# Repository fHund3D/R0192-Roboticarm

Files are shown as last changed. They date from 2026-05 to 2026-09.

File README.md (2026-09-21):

# Roboticarm-R0192




Der **R0192** ist ein 6-Achsen-Roboterarm, der auf einem hybriden System aus SteadyWin- und RobStride-Aktuatoren basiert. Dieses Repository enthält das vollständige ROS 2 Jazzy-Ökosystem für die CAN-Bus-Kommunikation, die Hardware-Abstraktion, die Bahnplanung via MoveIt 2 sowie ein Arduino-basiertes Hall-Sensor-Homing.

Die gesamte Steuerungslogik (MoveIt 2, ros2_control, CAN-Treiber) läuft auf einem **Raspberry Pi 5**. Eine zentrale **Betriebszustands-Maschine** (`robot_state_manager`) koordiniert Motor-Enable, Jogging, MoveIt-Ausführung, Homing und Notaus als sich gegenseitig ausschließende Zustände. Bedient wird der Arm über ein **RViz-Jog-Panel**, das gezielt zu einem Teach-Pendant-Ersatz ausgebaut wird (später ggf. durch ein echtes Hardware-Teach-Pendant ersetzbar); ein **Web-Interface** (`r0192_remote`) bleibt eine optionale Zukunftsoption. Foxglove Studio spielt nur eine kleine Rolle zum Debuggen. **Alle sechs Aktuatoren sind inzwischen beschafft und montagebereit**; softwareseitig sind die GDS68- und RS05-Antriebsstränge an je einer Achse verifiziert, die Inbetriebnahme der übrigen Achsen läuft.

---

## 🚀 Projekt-Roadmap

### Software (ROS 2 & OS)
- [x] OS-Setup: Ubuntu 24.04 & ROS 2 Jazzy Installation
- [x] Workspace & Paketstruktur initialisiert
- [x] Treiber-Integration: SteadyWin GDS68 (Achse 1–3)
- [x] Treiber-Integration: RobStride RS05 (Achse 4–6)
- [x] CAN-Kommunikation & Hardware Interface (ros2_control, 100 Hz, Closed-Loop)
- [x] URDF/XACRO Modellierung inkl. 3D-Visualisierung & Kollisionsgeometrien
- [x] MoveIt 2 Integration — Bahnplanung & Trajektorienausführung auf Achsen 1 + 4 verifiziert
- [x] Encoder-Homing beim Start (Hardware Interface setzt internen Nullpunkt)
- [x] `foxglove_bridge` in Bringup integriert (Debug-Tool, Port 8765, `use_foxglove:=true`)
- [x] **Homing-Sequenz** mit TLE4905L Hall-Sensoren — Arduino-Firmware (Achse 1) + ROS-Service `/homing` in `r0192_hardware` eingebettet; zweiseitiger Kantenanlauf (Kante A → Überfahren → Kante B → Mitte) implementiert
- [x] **RViz Jog-Panel / Teach-Pendant** (`r0192_rviz_plugins`) über MoveIt Servo: 3 Modi (Joints / Cartesian / Tool), Speed-Slider, Press-and-Hold
- [x] **Zentrale Zustandsmaschine** (`robot_state_manager` + `r0192_interfaces`): 5 exklusive Zustände DISABLED / HOLD / JOG / MOVEIT / HOMING via `/set_robot_state` + `/robot_state`
- [x] **Notaus** (`/e_stop`) — erzwingt DISABLED aus jedem Zustand, latchender Treiber-Torque-Cut (GDS68 `Estop()`, RS05 stop) + Treiber-Reset (`/robot_reset` → `Clear_Errors`) zur Wiederinbetriebnahme
- [x] **Programm-System** (`r0192_program_executor`) — industrielle Trennung Engineering (YAML in VS Code, JSON-Schema-Validierung) ↔ Operations (RViz-Run-Panel „R0192 Program"). Action `/execute_program`, KRL/Pilz-Steps `ptp`/`lin`/`circ` (+ Legacy `move_j`/`move_l`/`wait`), Stop-at-each-point **und** Pilz-Blend-Modus mit `c_dis`, Pause/Resume/Speed-Override, Punkt-Teach. Ersetzt für die Programmierung das ursprünglich geplante Web-Interface
- [ ] **Aktuell: Hardware-Test Homing** — Arduino + Magnet an Achse 1 anschließen und end-to-end validieren
- [ ] **Aktuell: RViz-Jog-Panel zum Teach-Pendant ausbauen** — bedienerfreundlich möglichst nah an ein echtes Teach-Pendant (später ggf. durch ein Hardware-Pendant ersetzbar); ein Web-Interface (`r0192_remote`) bleibt optionale Zukunftsoption
- [ ] **Hardware-Notaus über Schütz/Relay** — schaltet die 48-V-Versorgung hart ab (zusätzlich zum latchenden Treiber-Torque-Cut); laufenden Homing-Sweep abbrechen
- [ ] Echtzeit-Optimierung (RT-Kernel & CPU-Shielding auf RPi 5)

#### Projektstruktur

```
roboticarm_r0192_ws/
├── src/
│   ├── r0192_bringup/         # Bringup Sequenz (real + simuliert)
│   ├── r0192_canbus/          # CAN-Bus Treiber: GDS68, RS05, CanCommunication
│   ├── r0192_controller/      # JTC-Konfiguration, manueller Slider-Node
│   ├── r0192_description/     # URDF/XACRO, STL-Meshes, RViz-Konfiguration
│   ├── r0192_interfaces/      # Custom msgs/srvs: RobotState, SetRobotState
│   ├── r0192_hardware/        # ros2_control HW-Interface + robot_state_manager
│   ├── r0192_moveit/          # MoveIt 2: SRDF, Kinematik, Planung, Servo, Launch
│   ├── r0192_rviz_plugins/    # RViz Jog-Panel / Teach-Pendant (Operator-Panel)
│   └── r0192_remote/          # (Geplant) Web-Interface als Operator-Pendant
├── doku/                      # Datenblätter & Treiber-Dokumentation
├── build/                     # Build-Artefakte (ignoriert)
├── install/                   # Install-Artefakte (ignoriert)
└── log/                       # Logs (ignoriert)
```

#### System-Architektur

```
RViz Jog-Panel  /  Web-Interface (geplant)        Debug-Tools (optional)
  │  /set_robot_state, /e_stop                     RViz  ◄──  ROS-Topics
  │  /robot_state (latched)                        Foxglove ◄─ foxglove_bridge (:8765)
  ▼
robot_state_manager  (zentrale Zustandsmaschine)
  │  koordiniert: /robot_enable, switch_controller, pause_servo, /homing
  ├──────────────► MoveIt 2 + Servo
  │                     │
  ▼                     ▼
ros2_control (100 Hz, Closed-Loop)  ──►  arm_controller / gripper_controller
                 │
         R0192SystemHardware
          ├─ /robot_enable Service (Motor-Torque an/aus)
          ├─ /homing Service (eingebettet, HomingController)
                 │
    ┌────────────┴────────────┐
GDS68Driver              RS05Driver
(Achsen 1–3)             (Achsen 4–6)
    └────────────┬────────────┘
             SocketCAN (can0, 1 Mbit/s)
             MKS CANable Pro → Motoren
                 │
    Arduino Uno R3 (je 1 pro Achse)
    TLE4905L Hall-Sensor + MCP2515
    Homing-Node (CAN-ID 0x100, Codes in Data[0]: CMD_ARM/DETECTED/ERROR)
```

#### Betriebszustände (Robot State Manager)

Der `robot_state_manager` ist die *Single Source of Truth* für den Betriebszustand. Vorher war der Zustand implizit über drei verstreute Flags verteilt (`motors_enabled_`, Homing-aktiv, Servo-Pause) — jetzt 5 exklusive Zustände mit erzwungenen Übergängen:

| Zustand | Motor-Torque | `arm_controller` | Servo | Bedeutung |
| :--- | :--- | :--- | :--- | :--- |
| `DISABLED` | aus | inaktiv | pausiert | Idle, drehmomentfrei (Startzustand) |
| `HOLD` | an | inaktiv | pausiert | Servos an, Hardware hält letzte Soll-Pos |
| `JOG` | an | aktiv | aktiv | Teach-Pendant über MoveIt Servo |
| `MOVEIT` | an | aktiv | pausiert | move_group darf Trajektorien ausführen |
| `HOMING` | an | (Homing managed) | pausiert | Homing-Sequenz läuft |

Übergänge: `DISABLED ⇄ HOLD`, und aus `HOLD` heraus `→ JOG / MOVEIT / HOMING` (jeweils zurück nach `HOLD`). `/e_stop` erzwingt `DISABLED` aus **jedem** Zustand und kappt das Drehmoment **auf Treiber-Ebene** (GDS68 `Estop()` 0x002 latchend, RS05 stop). Die Treiber sind danach bewusst in einem Fehlerzustand „gefangen" — `/robot_reset` (→ Hardware `Clear_Errors` / RS05-Fault-Clear) löst das, erst dann ist `DISABLED→HOLD` wieder erlaubt. Clients (RViz-Panel, künftiges Web-Interface) steuern ausschließlich über `/set_robot_state` und spiegeln das latched `/robot_state` — nie direkt `/robot_enable` / `/homing` / `pause_servo`.

### Hardware & Mechanik
- [x] Kinematische Auslegung & Motorauswahl
- [x] Grobes mechanisches Design (CAD)
- [x] Beschaffung **aller 6 Aktuatoren** abgeschlossen (4× SteadyWin GIM @ GDS68, 2× RobStride RS05)
- [ ] Detail-Konstruktion & Optimierung der Steifigkeit
- [ ] Full-Scale 3D-Druck Prototyping (PLA/PETG)
- [ ] **Geplant:** Substitution kritischer Strukturbauteile durch CNC-Aluminium
- [ ] **Steuerungs- & Versorgungsschrank** (Item-/Profil-5-Alu, 20×20) — separates Gehäuse für beide Netzteile, ODrive Regen Clamp & Raspberry Pi als externe Steuerung/Stromversorgung des Arms

### Elektronik (PCB Design)
- [x] Schaltungskonzept & Leistungsplanung
- [x] Design Daisy-Chain PCB (PCB 2) - *Draft*
- [ ] Design Breakout-Board (PCB 1) - *Main Power Distribution*
- [ ] Not-Aus-Schütz 48 V aufbauen (Konzept steht: [`doku/estop_konzept.md`](doku/estop_konzept.md))
- [ ] PCB-Fertigung (PCBWay) & Bestückung
- [ ] Systemintegration & EMV-Tests

---

## 🛠 Technische Spezifikationen

### Achskonfiguration

> **Alle sechs Aktuatoren sind beschafft.** Achsen 1–4 nutzen SteadyWin-GIM-Motoren am **GDS68**-Treiber (11-bit-Standard-CAN), Achsen 5–6 RobStride **RS05** (29-bit-Extended-CAN). Achse 4 wurde von RS05 auf einen **GIM6010-8** umgestellt (24 V, ohne Bremse — der zuerst beschaffte Motor); Achsen 1–3 sind die 48-V-Varianten **mit Bremse** — sie legen den größten Weg zurück und tragen die größte Last; die Bremse hält sie stromlos in Position und verhindert ein Zusammenfallen des Arms ohne Strom. Achsen 5–6 sind RS05 @ 48 V.

| Achse | Motor | Treiber | Spannung / Bremse | Besonderheit | Lagerung | Status |
| :--- | :--- | :--- | :--- | :--- | :--- | :--- |
| **Axis 1** | [GIM6010-8](https://openelab.de/products/steadywin-gim6010-8-planetengetriebemotor?variant=54009308873041) | GDS68 | 48 V · mit Bremse | High Torque Base | [Kreuzlager RU66](https://de.aliexpress.com/item/1005008094900625.html) | ✅ Vorhanden |
| **Axis 2** | [GIM8108-8](https://openelab.de/products/steadywin-gim8108-8?variant=54041139609937) | GDS68 | 48 V · mit Bremse | Hauptausleger | [Kreuzlager RU42](https://de.aliexpress.com/item/1005008094900625.html) | ✅ Vorhanden |
| **Axis 3** | [GIM6010-8](https://openelab.de/products/steadywin-gim6010-8-planetengetriebemotor?variant=54009308873041) | GDS68 | 48 V · mit Bremse | Ellenbogen | - | ✅ Vorhanden |
| **Axis 4** | [GIM6010-8](https://openelab.de/products/steadywin-gim6010-8-planetengetriebemotor?variant=54009308873041) | GDS68 | 24 V · ohne Bremse | Zuerst beschaffter Motor (ersetzt RS05) | - | ✅ Vorhanden |
| **Axis 5** | [RS05](https://openelab.de/products/robstride05-qdd-55nm-joint-motor-robotik?variant=52331724931409) | Intern | 48 V | 1:2 Übersetzung (Torque) | [Kreuzlager RU28](https://de.aliexpress.com/item/1005008094900625.html) | ✅ Vorhanden |
| **Axis 6** | [RS05](https://openelab.de/products/robstride05-qdd-55nm-joint-motor-robotik?variant=52331724931409) | Intern | 48 V | Endeffektor Rotation | - | ✅ Vorhanden |

> **Code-Hinweis:** Achse 4 ist jetzt ein GIM6010-8 am **GDS68**-Treiber (11-bit-Standard-CAN) statt bisher RS05 (29-bit-Extended-CAN). Im Hardware-Interface/Treiber-Mapping ist Achse 4 noch der RS05-Zuordnung zugewiesen — die Code-Migration steht aus.

### Elektronik & Steuerung
* **Recheneinheit:** Raspberry Pi 5 (8GB RAM)
* **CAN-Interface:** MKS CANable Pro (Isoliert), SocketCAN (`can0`)
* **CAN-Bitrate:** 1 Mbit/s (info: 500 kbit/s GDS68 Werkseinstellung)
* **Energieversorgung:**
    * Bus-Spannung: 48 V — MeanWell LRS-600N2-48
    * Logik-Spannung: 5 V — MeanWell LRS-50
    * Steuerspannung Not-Aus-Kette: 24 V — separates Netzteil, nur für Schütz- und Relaisspulen
    * Regen-/Bremsenergie: [ODrive Regen Clamp](https://eu.odriverobotics.com/shop/odrive-regen-clamp) am 48-V-Bus — verhindert Überspannung beim Abbremsen/Rückspeisen der Motoren (2 Ohm und 50W Widerstand)
* **Steuerungs- & Versorgungsschrank:** separates Gehäuse aus Item-/Profil-5-Aluprofilen (20×20) — nimmt beide Netzteile, die Regen Clamp und den Raspberry Pi auf und bildet die externe Steuerung & Stromversorgung des Arms
* **Umbilical-Steckverbindung (Schrank ↔ Arm):** Heavy-Duty-Rechteckstecker im **Han-E-Format, 24-polig** (Typ HDC-HE-024, Harting-Han-24E-kompatibel) — 16 A/Kontakt, 500 V, 0,5–6 mm² Schraubanschluss, Metallgehäuse (Schirm-/PE-Anbindung), IP65. Führt 48 V, 5 V, Bremse (Achsen 1–3) und CAN in einem Stecker; CAN-Trio in einer Ecke mit GND-Guard, Kabelschirm aufs Metallgehäuse
* **Homing-Sensorik:** TLE4905L Hall-Effekt-Sensoren, je ein Node pro Achse — Prototyp Achse 1 mit Arduino Uno R3 + MCP2515, Zielhardware **XIAO-ESP32-S3 (natives TWAI)** auf der Daisy-Chain-Platine
* **Haltebremsen:** SteadyWin STW-S035 (24 V / 0,64 A, stromlos geschlossen), **PWM-gechoppt aus 48 V** über eine Low-Side-Endstufe pro Achse (Anzug 100 % Duty ~150 ms, Halten ~10,4 % Duty ≈ 0,7 W). **Am Arm liegt kein 24-V-Netz** — das 24-V-Netzteil im Schrank versorgt nur die Not-Aus-Kette.
* **Not-Aus (Hardware, geplant):** DC-Schütz in der 48-V-Schiene mit Selbsthaltung und Wiederanlaufschutz, Steuerkette über ein eigenes 24-V-Netzteil. Konzept: [`doku/estop_konzept.md`](doku/estop_konzept.md)
* **Schnittstellen (Platine):** WAGO 2601-3104 (Power-Durchschleife + Motorabzweig), Phoenix PTSM 0,5/3-2,5-V-THR (CAN), JST PH B3B-PH-K (Hall + Bremse) — Details in [`PCB/pcb_daisy_chain.md`](PCB/pcb_daisy_chain.md)

#### Verkabelung

Auslegung mit dem **200%-Kurzzeit-Peak** der Netzteile (48 V: 12,5 A Dauer → ~25 A Peak). Cu hat thermische Trägheit — der Peak ist eher für die **Schutzorgane** (träge Sicherung) relevant als für den Querschnitt.

| Kreis | Querschnitt | Kabeltyp |
| :--- | :--- | :--- |
| **48 V Trunk** (Box → Arm-Basis) | 2,5 mm² (≈14 AWG) | Silikon-Litze, feindrähtig (Klasse 5/6) |
| 48 V → Motor (Abzweig) | 1,0–1,5 mm² | Silikon-Litze (Achse 2 / GIM8108 → 1,5 mm²) |
| **5 V Logik** | 1,0 mm² (≈18 AWG) | Silikon-Litze (Querschnitt wegen Spannungsabfall, nicht Strom) |
| Bremse (Achsen 1–3, falls separat) | 0,5–0,75 mm² | Silikon-Litze (wenig Strom, kurzer Inrush) |
| **CAN** | 2×2×0,34 mm² | geschirmte, verdrillte CAN-Busleitung, **120 Ω** |

**Bewegung an den Gelenken** ist entscheidend für die Lebensdauer:

- **Drehachsen 1, 4, 6** (tordieren) → **torsionsfähige Roboterleitung** (z. B. Lapp ÖLFLEX ROBOT, igus chainflex), keine reine Biege-Schleppkettenleitung.
- **Biegeachsen 2, 3, 5** → Schleppketten-/Dauerbiege-Leitung genügt.
- Innerhalb eines Glieds (unbewegt) → einfache Silikon-Litze.

**CAN-Hinweise:** dediziertes 120-Ω-Buskabel (nicht zwei Adern aus dem Powerkabel), `CAN_GND` als Referenz mitführen, Schirm **steuerboxseitig** auf PE/Metallgehäuse (Han-E-Stecker); 48 V und CAN nicht ungeschirmt im selben Mantel bündeln.

**Konkrete Kabelauswahl (igus chainflex, Stand 2026-07):** Für das Hobby-Budget bewusst pragmatisch gewählt — eine Power-Kabelsorte für alles, günstige PVC-Busleitung statt teurer Torsionsvariante.

| Verwendung | igus Art-Nr. | Aufbau | Notiz |
| :--- | :--- | :--- | :--- |
| Power-Durchschleife 48 V + 5 V (Daisy-Chain) | **CF77.UL.15.04.D** | 4G1,5, PUR | Zwei getrennte Paare: 48 V / 48 V-GND + 5 V / 5 V-GND. GN-YE-Ader als vollwertiger Rückleiter nutzen (zulässig, da einheitliches GND-Netz). Kein gemeinsamer GND-Rückleiter — sonst summiert sich der Rückstrom auf dem Basissegment über 1,5 mm². |
| CAN-Bus-Durchschleife | **CFBUS.PVC.021** | (2×0,5)C, geschirmt | Biege-/Energieketten-Leitung (PVC), **keine Torsionsleitung**. Torsions-Upgrade (CFROBOT8.PLUS.022, CAN, torsionsfest) bewusst aus Kostengründen zurückgestellt — an rotierenden Gelenken später ggf. nur das kurze Gelenkstück tauschen. |
| PCB → Motor (Abzweig) | **CF77.UL.15.04.D** | 4G1,5, PUR | Kurz/statisch; nur 48 V + GND genutzt (CAN separat über die Busleitung). Bei hohem Motor-Peak (GIM8108 ~22 A) je 2 Adern parallel für 48 V bzw. GND → ~3 mm². Für Achse 1 (GIM6010 ~18 A) / Achse 4 (RS05 ~11 A) genügt eine Einzelader. |

> **Bezug:** igus liefert auch an Privatkunden über den Online-Shop, ab 1 m Länge ohne Mindestbestellwert. Shop-Preise sind netto — zzgl. MwSt., Kupferzuschlag und Versand. CFBUS.PVC.021 ~3,35 €/m, CF77.UL.15.04.D ~3,52 €/m (zzgl. Zuschläge).

**Materialkosten (grob, DE-Retail):** Silikon-Litze für Power/5V/Bremse ist günstig (~30–50 €), CAN-Leitung ~15–25 €. Kostentreiber ist die Torsions-/Roboterleitung an den Drehachsen. Gesamt: **~60–100 €** maker-pragmatisch (Silikon-Litze überall), **~120–220 €** mit Marken-Roboterleitung an den Gelenken; dazu Kleinkram (Aderendhülsen, Schrumpfschlauch, Gewebeschlauch) ~25–50 €.

> **Hinweis zu URDF-Werten:** Alle Gelenkgrenzen, Trägheitsmomente und Schwerpunkte in der URDF sind derzeit Platzhalter und werden nach Abschluss des CAD-Designs mit realen Werten befüllt.

---

---

## Quickstart (RPi)

```bash
# 1. CAN-Interface hochfahren (einmalig pro Boot)
sudo ip link set can0 up type can bitrate 1000000

# 2. Build (nach Code-Änderungen)
cd ~/roboticarm_r0192_ws
colcon build --symlink-install
source install/setup.bash

# 3. Roboterarm starten (ros2_control + MoveIt + RViz)
ros2 launch r0192_bringup real_robot.launch.py

# 4. Optional: Foxglove-Bridge für Remote-Debug mitstarten
ros2 launch r0192_bringup real_robot.launch.py use_rviz:=false use_foxglove:=true

# 5. Bedienung über die Zustandsmaschine (oder das RViz Jog-Panel)
#    Motoren scharf schalten (DISABLED -> HOLD):
ros2 service call /set_robot_state r0192_interfaces/srv/SetRobotState "{requested_state: 1}"
#    MoveIt-Ausführung freigeben (HOLD -> MOVEIT):
ros2 service call /set_robot_state r0192_interfaces/srv/SetRobotState "{requested_state: 3}"
#    Homing starten (HOLD -> HOMING, kehrt automatisch nach HOLD zurück):
ros2 service call /set_robot_state r0192_interfaces/srv/SetRobotState "{requested_state: 4}"
#    Notaus (erzwingt DISABLED aus jedem Zustand, latchender Treiber-Stop):
ros2 service call /e_stop std_srvs/srv/Trigger {}
#    Reset nach Notaus (löst die Treiber-Fehler, nötig vor erneutem Enable):
ros2 service call /robot_reset std_srvs/srv/Trigger {}

# Aktuellen Zustand beobachten (latched)
ros2 topic echo /robot_state

# Homing-Parameter zur Laufzeit anpassen (optional)
ros2 param set /r0192_homing homing_vel 0.1
ros2 param set /r0192_homing zero_offset 0.05
```

> **Hinweis:** `/homing` und `/robot_enable` existieren weiterhin als Low-Level-Services, sollten aber **nicht direkt** aufgerufen werden — das umgeht die zentrale Zustands-Erzwingung. Immer über `/set_robot_state` gehen.

> **Homing-Ablauf (Achse 1):** Pi sendet CAN `0x100` (`CMD_ARM`) → Arduino scharf gestellt → Achse sweept langsam zum Magneten → TLE4905L erkennt Kante A → Arduino antwortet `0x100`/`Data[0]=0xFF` (`RSP_DETECTED`) → Pi überfährt ~25°, fährt von der Gegenseite zurück bis Kante B → Mitte = (P1+P2)/2 → Software-Home-Offset im GDS68-Treiber gesetzt (nicht `Set_Linear_Count`, da kontinuierlicher Mehrumdrehungs-Encoder).

---

## Roboterprogramme (Engineering in VS Code, Ausführung über ROS 2)

Das Projekt folgt der industriellen Trennung **Engineering ↔ Operations** (siehe [doku/program_ide_plan.md](doku/program_ide_plan.md)): Programme werden in **VS Code** geschrieben (YAML mit Schema-Validierung), ausgeführt werden sie vom Backend **`r0192_program_executor`** über die Action **`/execute_program`** — per CLI oder über das **RViz-Run-Panel „R0192 Program"** (`r0192_rviz_plugins/ProgramPanel`, erscheint automatisch beim `real_robot.launch.py`-Start): Programm wählen, Run/Stop, Live-Markierung des laufenden Steps, Status „Step X / Y". Das Panel ist bewusst runtime-only — editiert wird ausschließlich in VS Code.

**Dateien** (im Repo, git-versioniert):

```
programs/
├── points.yaml          # Punktdatenbank: benannte Ziele (joint / pose)
└── program_*.yaml       # Programme: Steps ptp / lin / circ (KRL/Pilz) + wait
doku/schemas/            # JSON Schemas = Source of Truth (VS Code + Loader)
```

**Schreiben in VS Code:** Die empfohlene Extension `redhat.vscode-yaml` (siehe `.vscode/extensions.json`) validiert beide Dateitypen live gegen die Schemas in `doku/schemas/` (Mapping in `.vscode/settings.json`): ungültige Step-Typen/Felder werden markiert, gültige Felder autocompleted, Hover zeigt Doku. Snippets: `r0192-program` (neues Programm), `ptp`, `lin`, `circ`, `wait`, `point-joint`, `point-pose` (plus `move_j`/`move_l` als deprecated Aliase).

**Step-Vokabular:** Zwei koexistierende Sätze, beide gültig:

| Step | Bewegung | Parameter |
|---|---|---|
| `ptp` | Punkt-zu-Punkt (Pilz PTP), joint- oder pose-Ziel | `vel`, `acc`, `c_dis` |
| `lin` | Kartesische Gerade (Pilz LIN), nur pose-Ziel | `vel`, `acc`, `c_dis` |
| `circ` | Kreisbogen (Pilz CIRC) über `via`-Punkt zum Ziel, beide pose | `via`, `vel`, `acc`, `c_dis` |
| `wait` | Pause (Sekunden) | `duration` |
| `move_j` / `move_l` | **deprecated** — Legacy OMPL / KDL, weiterhin lauffähig | `velocity`, `acceleration` |

Wichtige Regeln: Programme referenzieren Punkte **nur per Name** aus `points.yaml` (keine Inline-Posen); `vel`/`acc` (bzw. `velocity`/`acceleration`) sind **MoveIt-Skalierungsfaktoren (0, 1]**, keine physikalischen Geschwindigkeiten; `c_dis` ist der Blend-Radius in Metern (0 = Halt am Punkt), nur im Blend-Modus wirksam.

**Zwei Run-Modi** (Goal-Feld `blend`, im Run-Panel der Toggle „Blend through (Pilz)"):
- `blend: false` (Default) — *Stop at each point*: jeder Move einzeln geplant/ausgeführt, `c_dis` ignoriert, `circ` abgelehnt.
- `blend: true` — *Blend through*: zusammenhängende Move-Steps gehen als **eine** Pilz-`MotionSequenceRequest` an `/sequence_move_group` (`blend_radius = c_dis`, letztes Segment hält). Pflicht für `circ`. Für `circ` müssen Start, `via` und Ziel **nicht-kollinear** sein (sonst „Plane for motion is not properly defined"). `wait`-Steps trennen eine Sequenz.

**Simulationsmodus** (Goal-Feld `dry_run`, im Run-Panel der Toggle „Simulate (dry run)"): `dry_run: true` plant das ganze Programm und animiert es **nur als RViz-Geist** (`/display_planned_path`) — der echte Arm bewegt sich **nicht**, der Roboterzustand bleibt unangetastet (kein MOVEIT, Motoren bleiben aus/an wie sie sind), `wait`-Steps werden übersprungen. Läuft aus **jedem** Zustand und ist die saubere Vorschau vor dem echten Lauf. Häkchen raus → echter Lauf auf dem Arm.

**Ausführen** (Arm muss in `HOLD` sein; der Executor schaltet selbst `HOLD → MOVEIT → HOLD`):

```bash
# Stop at each point (Default)
ros2 action send_goal /execute_program \
  r0192_interfaces/action/ExecuteProgram "{program_path: program_demo.yaml}" -f

# Blend through (Pilz-Sequenz mit c_dis-Blending; Pflicht für circ)
ros2 action send_goal /execute_program \
  r0192_interfaces/action/ExecuteProgram "{program_path: program_blend_demo.yaml, blend: true}" -f
```

Relative Pfade werden gegen `programs/` aufgelöst (Parameter `programs_dir`/`points_file` des Executor-Nodes). Action-Cancel stoppt die laufende Bewegung (`MoveGroupInterface::stop()`) und kehrt sauber nach `HOLD` zurück. Nach einem Notaus (`/e_stop`) fasst der Executor den Zustand nicht an — die Wiederinbetriebnahme läuft wie immer über `/robot_reset` + `/set_robot_state`.

**Pause, Resume & Speed-Override** (auch als Button/Slider im Run-Panel):

```bash
# Pause nach dem aktuellen Step (Zustand bleibt MOVEIT, Arm hält Position)
ros2 service call /pause_program std_srvs/srv/Trigger {}
ros2 service call /resume_program std_srvs/srv/Trigger {}

# Globaler Speed-Override (klemmt auf [0.1, 1.0], wirkt ab dem NÄCHSTEN Step)
ros2 service call /set_program_override r0192_interfaces/srv/SetProgramOverride "{override: 0.3}"
ros2 topic echo /program_override --once     # autoritativer Ist-Wert (latched)
```

**Punkte teachen** (Phase 4, auch über die „Points"-Gruppe im Run-Panel): `/teach_point` speichert die aktuelle Position (joint oder pose, nur in `HOLD`/`JOG`), `/list_points` listet, `/delete_point` löscht. Explizite Werte editiert man direkt in `points.yaml` (VS Code, schema-validiert) — Achtung: ein Teach/Delete-Rewrite erhält Hand-Kommentare nicht.

---

## Beitragen

1. Fork das Repository
2. Erstelle einen Feature-Branch (`git checkout -b feature/AmazingFeature`)
3. Commit deine Änderungen (`git commit -m 'Add some AmazingFeature'`)
4. Push zum Branch (`git push origin feature/AmazingFeature`)
5. Öffne einen Pull Request

## Lizenz

Dieses Projekt ist unter der MIT License lizenziert - siehe die [LICENSE](LICENSE) Datei für Details.

## Kontakt

Bei Fragen oder Problemen: Erstelle ein Issue im GitHub Repository.

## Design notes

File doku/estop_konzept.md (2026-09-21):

# R0192 Not-Aus: Hardware-Abschaltung der 48-V-Schiene

**Status: Entwurf 2026-09-21 (Steuerspannung auf ein eigenes 24-V-Netzteil geändert) — nicht gebaut, nicht bestellt.** Auslegung und Teileauswahl stehen, die Entscheidungen unter „Offene Punkte" fehlen noch.

Der bestehende Software-Not-Aus (`/e_stop` → `/robot_estop` → GDS68 `Estop()` / RS05 `Motor_Stop_Running`) kappt das Drehmoment auf **Treiber-Ebene**. Das ist eine Software-Kette über CAN — sie setzt voraus, dass Pi, CAN-Bus und Treiber-Firmware leben. Dieses Dokument beschreibt die **zweite, davon unabhängige Ebene**: ein Schütz, das die 48 V physisch trennt.

---

## Randbedingungen

| | |
| --- | --- |
| Zu schaltender Kreis | 48 V DC, **12,5 A Dauer**, ~25 A für 5 s (200-%-Peak des LRS-600N2) |
| Verfügbare Hilfsspannungen | Am Arm **nur 5 V** (LRS-50) und **48 V** — es gibt kein 24-V-Netz im Arm, die Haltebremsen werden PWM-gechoppt direkt aus 48 V betrieben (s. [PCB-Doku](../PCB/pcb_daisy_chain.md), „Bremsen-Endstufe"). **Für die Not-Aus-Kette steht ein separates 24-V-Netzteil zur Verfügung** (vorhanden, bisher ungenutzt). |
| Bus-Kapazität hinter dem Schütz | 6 × ~300 µF ≈ **1,8 mF** (C2/C3/C14 je Board) plus Treiber-Eingangskapazität |
| Rückspeisung | ODrive Regen Clamp am Bus, klemmt auf ~50 V |
| Not-Aus-Taster | **vorhanden** (Pilz, rastend, Öffnerkontakt) |
| Einbauort | Steuerungs- & Versorgungsschrank (Item-Profil-Gehäuse), zwischen Netzteil und Han-E-24-Umbilical |

---

## Einbaureihenfolge

```
230 V AC ─[Hauptschalter/FI]─┬─► MeanWell LRS-600N2 (48 V)
                             │        │
                             │      [F2: 30 A KFZ-MIDI oder 20 A träge]
                             │        │
                             │      ┌─┴─ R_pre 47 Ω ─ K3 ─┐   Vorladung
                             │      │                     │
                             │      └═╪═ K1 (DC-Schütz) ══┘
                             │        │
                             │   ┌────┴──────────────┬─────────────────────┐
                             │   │                   │                     │
                             │  ODrive Regen Clamp  Bleeder 10 k/2 W   Han-E 24 ─► Daisy-Chain-Boards
                             │  + 2 Ω / 50 W                                        ─► GDS68 / RS05
                             │
                             ├─► 24-V-Netzteil ──────────────────────────► Not-Aus-Kette (K1/K2/K3-Spulen)
                             │                                              galvanisch getrennt vom 48-V-Bus
                             │
                             └─► MeanWell LRS-50 (5 V) ──────────────────► Pi, CAN, Daisy-Chain-Logik
                                                                            NICHT geschaltet
```

**Drei Festlegungen, die dabei wichtig sind:**

1. **Die Regen Clamp hängt auf der Lastseite von K1.** Wird 48 V getrennt während der Arm fährt, speisen die Motoren über die Body-Dioden der Treiber-Brücken zurück. Läge die Clamp auf der Netzteilseite, hätte diese Energie keinen Abfluss mehr und die Busspannung liefe über die 72 V des GDS68 bzw. die 100 V von Q2/Elkos hinaus. Auf der Lastseite arbeitet sie unverändert weiter.
2. **Die 5 V werden nicht geschaltet.** Sonst rebooten Pi, CAN-Transceiver und alle sechs Homing-Nodes bei jedem Not-Aus, und die Diagnose ist genau dann weg, wenn man sie braucht. Die Motortreiber hängen ohnehin an 48 V.
3. **Die Steuerspannung wird vor dem Schütz abgegriffen**, sonst könnte sich K1 nie selbst einschalten.

**Warum nicht auf der 230-V-Seite trennen?** Billiger (AC-Schütze löschen im Nulldurchgang), aber das LRS-600 hat eine Hold-up-Zeit im zweistelligen Millisekundenbereich und danach entladen sich noch 1,8 mF Buskapazität. Dazu kommt ein Kaltstart des Netzteils bei jedem Not-Aus. Für einen Roboterarm ist DC-seitig trennen richtig.

---

## Steuerspannung: eigenes 24-V-Netzteil

**Entscheidung 2026-09-21: eigenes 24-V-Netzteil**, nicht aus dem 48-V-Bus abgeleitet.

| Variante | Bewertung |
| --- | --- |
| **5 V** (LRS-50) | In der 25-A-DC-Klasse gibt es praktisch keine 5-V-Spulen. Die Panasonic HE-V fängt bei 6 V an, und die Anzugsspannung liegt typisch bei 75 % der Nennspannung (≈ 4,5 V) — mit der Spulenerwärmung steigt sie weiter. Für ein Sicherheitselement zu knapp. |
| **aus 48 V abgeleitet** (z. B. Recom R-78HB12-0.5, 17–72 V → 12 V) | Funktioniert und spart ein Netzteil — hat aber eine unangenehme Rückkopplung: Bei einem Kurzschluss auf der Lastseite geht das LRS-600 in die Konstantstrombegrenzung, die Busspannung fällt unter den Eingangsbereich des Moduls, K1 fällt ab, der Kurzschluss ist weg, das Netzteil erholt sich, K1 zieht wieder an … Ein Schütz, das gegen einen Kurzschluss klappert, verschweißt. Die Selbsthaltung über K2 fängt das nach dem ersten Durchgang ab, aber die Abhängigkeit bleibt. |
| **eigenes 24-V-Netzteil** ✔ | Galvanisch unabhängig vom 48-V-Bus, damit existiert die Rückkopplung oben gar nicht. 24-V-Spulen sind der Industriestandard → größte Auswahl bei Schütz und Hilfsrelais. Bei ~80 mA Spulenstrom ist der Leitungsabfall zum Not-Aus-Taster irrelevant. |

**Strombedarf:** K1-Spule ~80 mA, K2 ~40 mA, K3 ~40 mA, Optokoppler ~10 mA → **unter 200 mA**. Jedes Kleinnetzteil genügt.

**Bedingung: gleicher Netzschalter und dieselbe Sicherung wie der Rest des Schranks.** Sonst kann die Steuerspannung stehen, während der Schrank scheinbar aus ist — genau die Überraschung, die man beim Arbeiten an der Verdrahtung nicht will.

Fällt das 24-V-Netzteil aus, fällt K1 ab: der Ausfall führt in den sicheren Zustand, und der Pi sieht es über den Statuseingang.

---

## Schaltung

```
+24 V ─[F3 0,5 A]─┬─ Not-Aus (Öffner 1) ─┬─[Reset-Taster NO]─┬─ K2-Spule ─ GND
                  │                      └─[K2 Kontakt 1]────┘   Selbsthaltung
                  │
                  ├─ K2 Kontakt 2 ─ Q1 (Pi GPIO) ─ K1-Spule ─ GND        48-V-Schütz
                  ├─ K2 Kontakt 3 ─ Q3 (Pi GPIO) ─ K3-Spule ─ GND        Vorladerelais
                  └─ K2 Kontakt 4 ─ Optokoppler ─► Pi GPIO (Eingang)     Status
```

Die 24-V-Masse der Steuerkette und die 48-V-Masse an **einem** Punkt im Schrank verbinden (Sternpunkt), damit Pi-Statuseingang und MOSFET-Source ein gemeinsames Bezugspotenzial haben. Der Optokoppler hält die 24 V trotzdem vom Pi fern.

Über K1- und K3-Spule je eine Freilaufdiode **in Reihe mit einer Z-Diode** (oder eine TVS, z. B. P6KE33A — V_RWM 28,2 V, sicher über den 24 V). Eine nackte 1N4007 verlangsamt den Spulenabfall spürbar, und beim Schütz heißt langsamer Abfall längerer Lichtbogen.

Q1/Q3: logic-level MOSFET (AO3400A o. ä.) mit **10 k Gate-Pulldown**. Die Pi-GPIOs sind beim Boot hochohmig — mit dem Pulldown ist der sichere Zustand „aus" der Default, auch während des Bootens und nach einem Absturz.

### Verhalten

| Ereignis | Wirkung |
| --- | --- |
| Not-Aus gedrückt | K2 fällt → K1 fällt → 48 V weg. Rein mechanisch, die Software kann das nicht überstimmen. |
| Not-Aus entriegelt | **Bleibt aus.** Die Selbsthaltung um den Reset-Taster ist unterbrochen, K2 zieht erst nach dem Drücken von Reset wieder an. Wiederanlaufschutz in Hardware. |
| Pi setzt GPIO low (`/e_stop`) | Q1 sperrt → K1 fällt. K2 bleibt angezogen, d. h. der Pi kann über `/robot_reset` wieder einschalten, ohne dass jemand zum Schrank läuft. |
| Pi bootet / stürzt ab | GPIO hochohmig → Pulldown → K1 offen. |
| 48 V oder Netzteil weg | Steuerspannung weg → K1 offen. |

Der Preis für den Komfort in Zeile 4: nach einem **Software**-Not-Aus kann die Software auch wieder einschalten. Der Hardware-Taster bleibt davon unberührt — der braucht immer den physischen Reset.

> **Minimalvariante ohne K2:** Die HEV2aN hat zwei Kontakte. Man kann Kontakt B als Selbsthaltung benutzen und K2 komplett sparen. Dann bricht aber auch jeder Software-Not-Aus die Selbsthaltung, und man muss nach *jedem* `/e_stop` physisch am Schrank quittieren. Für den Dauerbetrieb sauberer, für die Entwicklung lästig.

---

## Schütz K1

**Panasonic HEV2aN-P-DC24V** (HE-V-Serie, „High Capacity DC Cutoff Relays"), Mouser.

| | |
| --- | --- |
| Kontakte | 2 Form A, AgNi |
| Strom | 25 A |
| Schaltvermögen | 20 A @ 400 V DC (ein Kontakt), 25 A @ 600 V DC (beide in Serie), max. 1000 V DC |
| Spule | 6 / 9 / 12 / 15 / 24 V DC |

Bei 48 V ist das Teil massiv unterfordert — die Lichtbogenenergie skaliert mit U·I, und 400 V DC sind Faktor 8 über dem Arbeitspunkt. Genau dieser Abstand ist die Reserve, die man bei einem Sicherheitselement will.

**Beide Kontakte parallel** schalten: die Serienschaltung bringt nur mehr Spannungsfestigkeit, die hier niemand braucht, parallel gibt es thermische Reserve für den 25-A-Peak. (Beim Öffnen trägt der zuerst öffnende Kontakt den Lichtbogen allein — bei 48 V unkritisch.)

**Die typische Falle beim Aussuchen:** Distributor-Filter mischen Spulen- und Kontaktspannung. Ein TE T9AS1D12-48 ist eine **48-V-Spule** mit 30 A Kontakt — aber nur **30 V DC** Schaltvermögen. Die meisten „30 A"-Leistungsrelais sind 30 A / 250 V **AC** und 30 A / 30 V **DC**.

Alternative mit mehr Reserve, falls der Strom später steigt: Gigavac **GX11** / **GX14** (50–150 A, 12–800 V DC, Spule auch 24 V) — liegen aber bei ~100 €+.

---

## Vorladung (K3 + R_pre)

Hinter dem Schütz liegen ~1,8 mF, davor die geladenen Ausgangskondensatoren des LRS-600. Schließt K1 direkt, fließt ein Ausgleichsstrom, der nur durch den Leitungswiderstand begrenzt ist — drei-stellige Ampere für einige Mikrosekunden. Das verschweißt auf Dauer die Kontakte.

**Ablauf, vom Pi gesteuert** (K1 wird ohnehin nur vom Pi eingeschaltet, der Taster schaltet nur ab):

```
1. Q3 an   → K3 zieht an, Bus lädt über R_pre 47 Ω     τ = 47 Ω · 1,8 mF ≈ 85 ms
2. 500 ms warten                                        (≈ 6 τ, Bus auf > 99 %)
3. Q1 an   → K1 zieht an (beide Seiten gleiches Potenzial, kein Inrush)
4. Q3 aus  → K3 fällt ab (trennt spannungslos, K1 ist parallel)
```

R_pre: **47 Ω / 10 W Drahtwiderstand**. Spitzenstrom 48 V / 47 Ω ≈ 1 A, Energie pro Ladevorgang ½·C·U² ≈ 2,1 J — für einen 10-W-Typ ein Klacks. K3 kann ein beliebiges kleines 24-V-Relais sein: es schließt in 1 A und öffnet spannungsfrei.

> **Alternative ohne K3/Q3:** R_pre fest parallel zu den K1-Kontakten. Dann liegen beide Seiten immer auf gleichem Potenzial und der Inrush entfällt ohne jede Sequenz. Preis: nach dem Not-Aus rieseln dauerhaft ~22 mA in den Bus. Das reicht für kein Drehmoment und auch nicht für die Halte-PWM der Bremsen (147 mA pro Achse), aber „Bus ist garantiert spannungsfrei" gilt dann nicht mehr — beim Arbeiten am Arm muss man den Hauptschalter benutzen.

**Bleeder** 10 k / 2 W auf der Lastseite: entlädt die 1,8 mF nach dem Trennen in ~1 min auf ungefährliche Werte, Verlustleistung 0,23 W. Gespeicherte Energie ist mit ~2 J ohnehin harmlos, aber definierte Verhältnisse sind angenehmer.

---

## Bremsen beim Not-Aus

Die Haltebremsen sind stromlos geschlossen und hängen an 48 V — das Trennen lässt sie also **zwangsläufig** einfallen. Aber verzögert: solange die Busspannung aus den 1,8 mF noch steht und der ESP32 an 5 V weiterläuft, läuft auch die Halte-PWM weiter. Die Bremse fällt erst unter ~2,5 V mittlerer Spulenspannung, bei 10,4 % Duty also erst unter ~24 V Bus (Details in der [PCB-Doku](../PCB/pcb_daisy_chain.md), „Bremsen-Endstufe → Sicherheit").

**Vorschlag: Bus-Unterspannung auf dem vorhandenen Sense-Pin erkennen.** Der Bremsen-Sense (GPIO D3, Teiler R7 150 k / R8 6,8 k am Schaltknoten) misst in der PWM-**Aus**-Phase die Busspannung, weil der Knoten dann über D1 bzw. über die Spule am Bus hängt. Teilerverhältnis 6,8/156,8 = 0,0434 → 48 V ergeben 2,08 V am ADC, gut im Bereich.

```
Firmware: in der PWM-Aus-Phase samplen.
          U_bus < 40 V für > 2 ms  →  PWM = 0
```

Die Bremse fällt dann in ihren ~20 ms statt nach einigen hundert Millisekunden, **ohne zusätzliche Hardware** und ohne dass der ESP32 vom Pi informiert werden muss. Das ist der bessere der beiden Wege, die die PCB-Doku als offenen Punkt führt (die Alternative „Schütz trennt auch die 5 V" kostet CAN und Diagnose).

Zu verifizieren beim Bring-up: dass der Knoten in der Aus-Phase tatsächlich sauber am Bus liegt und der ADC-Wert nicht von der Freilaufphase verfälscht wird.

---

## ROS-Anbindung

Die Zustandsmaschine (`robot_state_manager`) bleibt unverändert, sie bekommt nur zwei zusätzliche Aktionen und einen Eingang:

| ROS-Schnittstelle | bisher | neu zusätzlich |
| --- | --- | --- |
| `/e_stop` | Treiber-Torque-Cut über `/robot_estop` | **danach** Q1 aus → K1 fällt |
| `/robot_reset` | `/robot_clear_faults` | Vorladesequenz, dann Q1 an |
| `/robot_state` | 5 Zustände | Not-Aus-Eingang (Optokoppler) erzwingt `DISABLED`, solange K2 abgefallen ist |

**Reihenfolge bei `/e_stop` ist wichtig:** erst der Treiber-Stop über CAN, dann ~50 ms später das Schütz. Dann sind die Endstufen bereits aus, bevor die Busspannung wegbricht, und die Regen Clamp muss weniger abfangen. Der Hardware-Taster geht natürlich direkt auf die Spule, ohne jede Verzögerung.

Drei GPIOs: 2 Ausgänge (Q1, Q3), 1 Eingang (Not-Aus-Status über Optokoppler, damit die 12 V nicht an den Pi gehen).

---

## Stückliste

| Pos | Teil | Bezug | ca. |
| --- | --- | --- | ---: |
| K1 | Panasonic **HEV2aN-P-DC24V** | Mouser | ~30 € |
| — | 24-V-Netzteil für die Steuerkette (≥ 200 mA) | **vorhanden** | — |
| K2 | Finder **55.34.9.024.0040** (4 Wechsler, 24 V DC) + Fassung 94.74 | Reichelt | ~12 € |
| K3 | kleines 24-V-Relais, 1 Schließer | Reichelt | ~4 € |
| R_pre | 47 Ω / 10 W Draht | Reichelt | ~2 € |
| Bleeder | 10 k / 2 W | Reichelt | ~1 € |
| Q1, Q3 | AO3400A + 10 k Pulldown | Mouser | — |
| — | P6KE33A (über K1/K3-Spule), 1N4007 | Mouser | — |
| F2 | KFZ-MIDI-Halter + 30 A | Reichelt | ~6 € |
| F3 | Feinsicherung 0,5 A träge + Halter | Reichelt | ~2 € |
| — | Reset-Taster (Schließer) | Reichelt | ~5 € |
| — | Optokoppler PC817 + 2,2 k Vorwiderstand | Mouser | — |

Not-Aus-Taster ist vorhanden. **Prüfen:** ob er einen zweiten Öffner für die Statusrückmeldung hat — sonst kommt der Status wie oben über K2 Kontakt 4.

---

## Grenzen

- **Kategorie 0 einkanalig.** Keine Zweikanaligkeit, keine Kontaktrückführung, kein Verschweiß-Nachweis. Wer das braucht, ersetzt K2 durch ein Sicherheitsrelais (Pilz PNOZ X2.8P, Phoenix PSR, Siemens 3SK1, ~80–130 €), das beide Öffner überwacht und die Rückmeldekontakte von K1 auswertet. Die übrige Schaltung bleibt gleich.
- **Laufendes Homing wird nicht abgebrochen.** Der `HomingController` fährt Achse 1 an `motors_enabled_` vorbei. Das Drehmoment ist nach dem Schütz zwar weg, aber der Abbruch-Hook in der Software fehlt weiterhin (s. `CLAUDE.md`, „v1-Grenze").
- **Kein PE-/Isolationskonzept** in diesem Dokument. 48 V SELV, aber der 230-V-Teil des Schranks ist ein eigenes Thema.

## Offene Punkte

- [ ] K2-Variante (Software darf wieder einschalten) vs. Minimalvariante (Selbsthaltung über K1-Kontakt B, immer physischer Reset) entscheiden
- [ ] Vorladung: Pi-sequenziert mit K3, oder R_pre fest parallel mit dem Rest-Rieselstrom
- [ ] Bus-Sense-Trip in der ESP32-Firmware umsetzen und beim Bring-up gegen die reale Einfallzeit messen
- [ ] Kontakte des vorhandenen Not-Aus-Tasters prüfen (Anzahl Öffner, DC-Angaben)
- [ ] Spulenleistung der HEV2aN aus dem Datenblatt gegen die Leistung des vorhandenen 24-V-Netzteils gegenrechnen (erwartet ~80 mA, Gesamtkette < 200 mA)
- [ ] 24-V-Netzteil auf denselben Netzschalter / dieselbe Sicherung legen wie das 48-V- und 5-V-Netzteil
- [ ] Platz und Montage im Steuerungsschrank (Hutschiene?) festlegen

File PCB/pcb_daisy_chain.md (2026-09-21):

# R0192 „Daisy Chain" Driverlink-PCB

Bus-Verteilplatine, **einmal pro Achse**. Schleift 48 V, 5 V und CAN von Node zu Node durch, zweigt die Motorversorgung ab, wertet den Homing-Hallsensor aus und steuert die Aktuator-Haltebremse. Ersetzt den Arduino-Uno-Prototyp (`microcontroller/r0192_homing.ino`) durch einen **XIAO-ESP32-S3** mit integriertem CAN-Controller (TWAI).

Identische Platine an jeder Achsposition: Bus-Termination per Schalter, positionsabhängige Verbraucher (Bremse) per Bestückungsvariante.

KiCad-Projekt: `PCB/KiCad/DriverDasyChain.*` (4 Lagen: F.Cu / In1 GND / In2 PWR / B.Cu)
Datenblätter: `PCB/R0192.pretty/Datenblätter/` (Bauteile) und `.../Kabel/` (CF77.UL.D, CFBUS.PVC)

---

## Funktionsblöcke

| Block | Umsetzung |
| --- | --- |
| Power-Durchschleife | J12 / J10 (4-polig): +5 V / GND / GND / +48 V. Bulk C2/C3/C14 = 3× 100 µF / 100 V, C4 100 nF / 100 V |
| 3,3 V-Erzeugung | U1 AP2112K-3.3 aus 5 V (C8 10 µ / C5 1 µ / C6 2,2 µ), EN an VIN, D3 SMAJ5.0CA am Eingang (bidirektional) |
| MCU | U2 XIAO-ESP32-S3 (Footprint `R0192:XIAO-ESP32-S3-DIP`, THT-Sockel), Versorgung über **3V3-Pin**, trennbar über SW2 (PCM12SMTR) — beim Flashen über USB öffnen, VBUS = NC |
| CAN-Transceiver | U4 SN65HVD230 (nativ 3,3 V), Rs auf GND (High-Speed), Vref NC, C7 100 nF |
| CAN-Bus | J1/J2 (CANH/CANL/SHLD), Schirm hybrid über R6 1 M ‖ C11 100 n; R10 (0 Ω) = harte Schirmauflage, **nur auf einem Board bestücken** |
| Terminierung | **Split-Termination**: R13 + R12 je 60,4 Ω in Reihe über den Bus, Mittelpunkt über C13 4,7 nF auf GND. Zuschaltbar über SW1 (CTS 219-2LPSTJ, **2-polig**, je ein Pol pro Zweig) — nur an den zwei physischen Busenden einschalten |
| CAN-TVS | D2 PESD12VL2BT (Symbol `NUP2105L`), CANH und CANL je gegen GND, sitzt direkt vor U4 |
| Motorabzweig | J4: CANH, CANL, GND, +48 V (Steckertyp s. u.) |
| Homing-Sensor | J5: 5 V / GND / OUT (Pin 1–3). R1 4,7 k Pull-up auf **3,3 V**, C10 1 nF, R9 6,8 k Serienschutz |
| Bremsen-Endstufe | J3 + F1 (PPTC) + Q2 + D1, Gate über U3 74AHCT1G125 (3,3 V → 5 V) |
| Status-LED | D4 (rot oder grün, 0603) + **R11 470 Ω** an **D2**, active high |
| UART-Debug | J6: GND / D6 / D7 / +3,3 V, TX/RX über R5 / R14 (220 Ω in Serie). Adapter-VCC **nicht** an Pin 4 (= 3,3-V-Schiene) |

---

## GPIO-Belegung (XIAO-ESP32-S3)

| Pin | GPIO | Funktion |
| --- | --- | --- |
| D0 | GPIO1 | **Bremse PWM** → U3 → R2 22 Ω → Q2 Gate |
| D1 | GPIO2 | **Hallsensor** (TLE4905L, über R9 6,8 k) |
| D2 | GPIO3 | **Status-LED** (R11 470 Ω, active high) — dadurch bleiben D4/D5 (SDA/SCL) für I²C frei |
| D3 | GPIO4 (ADC1_CH3) | **Bremsen-Schaltknoten-Sense** (Teiler R7 150 k / R8 6,8 k, C12 100 n) |
| D6 / D7 | GPIO43 / GPIO44 | UART TX / RX (Debug, J6) |
| D9 / D10 | GPIO8 / GPIO9 | **CAN RX / CAN TX** → U4 Pin 4 (R) / Pin 1 (D) |

> **Firmware:** `ESP32-TWAI-CAN` bzw. `driver/twai.h` statt `autowp/mcp2515`. CAN liegt auf D10/D9 (**nicht** D6/D7 — die sind UART0/Debug). CAN-Protokoll unverändert: achsenspezifische ID, `CMD_ARM` / `RSP_DETECTED` / `RSP_ERROR`.

> **Keine Sockel-Symbole mehr:** die früheren Hilfsstecker J7/J8/J9/J11 sind gelöscht; die Signale hängen direkt an U2. Grund: die vier Footprints lagen auf dem Board deckungsgleich auf denselben 14 Pads, und die eine Seite (J8) war gegenüber der physischen Lage zeilenverkehrt — nach der physischen Zuordnung wäre die Bremsen-PWM auf **D6 = UART0 TX** gelandet. Jetzt ist der XIAO-Footprint die einzige Wahrheitsquelle. D4, D5, D8 und VBUS haben No-Connect-Flags.

---

## Steckerkonzept & Kabel

**Prinzip:** Push-in-Klemmen für Power und Bus, JST PH dort, wo die Kabel für Klemmen zu dünn sind. Alles Top-Entry. Drei Bauteilnummern: WAGO 2601-3104 (3×), Phoenix PTSM 0,5/3-2,5-V-THR (2×), JST PH B3B-PH-K (2×), dazu eine Stiftleiste.

| Stecker | Typ | Footprint | Kabel / Ader |
| --- | --- | --- | --- |
| J12 / J10 Power | WAGO **2601-3104**, Push-in, Top-Entry, 17,5 A / AWG 26–14 | `TerminalBlock_WAGO:TerminalBlock_WAGO_2601-3104_1x04_P3.50mm_Vertical` | CF77.UL.15.04.D, alle 4 Adern, 1,5 mm², 21 A/Ader (igus) — Bus zieht max. 12,5 A |
| J4 Motor (CANH/CANL/GND/48 V) | WAGO **2601-3104**, Push-in, Top-Entry, 17,5 A / AWG 26–14 | `TerminalBlock_WAGO:TerminalBlock_WAGO_2601-3104_1x04_P3.50mm_Vertical` | 1,5 mm² Power + 0,5 mm² CAN im selben Block |
| J1 / J2 CAN | Phoenix **PTSM 0,5/3-2,5-V-THR**, Push-in, Top-Entry, 6 A / 160 V, **0,14–0,5 mm² (AWG 26–20)** | `TerminalBlock_Phoenix:TerminalBlock_Phoenix_PTSM-0,5-3-2.5-V-THR_1x03_P2.50mm_Vertical` | CFBUS.PVC.021, 0,5 mm² — **am Maximum der Klemme** |
| J5 Hall | **JST PH B3B-PH-K**, vertikal, Kontakt SPH-002T-P0.5S: 0,05–0,22 mm² (AWG 30–24), OD 0,9–1,5 mm, 2 A | `Connector_JST:JST_PH_B3B-PH-K_1x03_P2.00mm_Vertical` | 0,14 mm², OD 1,1 mm — beides mittig im Fenster |
| J3 Bremse | **dieselbe JST PH B3B-PH-K** (nur Pin 1+2 belegt, Pin 3 = Reserve + NC-Flag) | dito | 0,081 mm² (AWG 28), OD 0,8 mm — fest am Motor, nicht änderbar; Leiter im Fenster, OD 0,1 mm darunter |
| J6 UART-Debug | Stiftleiste 1×04 (Dupont) | `Connector_PinHeader_2.54mm:PinHeader_1x04_P2.54mm_Vertical` | — |

**Warum J5/J3 kein Klemmentyp sind:** das Bremskabel kommt fest aus dem Motor (Wechsel = Treiber demontieren) und hat 0,081 mm² — 42 % unter dem PTSM-Minimum von 0,14 mm². Der JST-PH-Kontakt deckt 0,05–0,22 mm² ab und passt nativ; nur die Isolations-OD liegt mit 0,8 mm knapp unter den geforderten 0,9 mm. **Abhilfe:** vor dem Krimpen ein kurzes Stück dünnen Schrumpfschlauch über die Isolierung schieben, dann greift der Zugentlastungsflügel. Der stromführende Leiterkrimp ist unkritisch. Zange ist vorhanden; ~24 Krimps über alle sechs Boards.

Zweimal dieselbe 3-polige B3B-PH-K, an J3 bleibt ein Pin frei — nützlich als Reserve, falls eine Bremsader durch Biegewechsel bricht. **Fehlerrichtung ist gutartig:** verliert die Bremsleitung Kontakt, fällt die Bremse ein (stromlos geschlossen).

**J3 Pin 3 bleibt bewusst unbelegt (entschieden 2026-09-15).** GPIO D5 (GPIO6) auf diesen Pin zu legen wurde geprüft und verworfen. Die Bremsadern werden selbst in das PHR-3-Gehäuse gecrimpt: Landet eine Ader in Position 3, liegt die Spule zwischen `BRAKE +48V` und dem GPIO, und bis zu 48 V / 34 Ω ≈ 1,4 A fließen über die Schutzdiode in die 3,3-V-Schiene (XIAO und ggf. U4 defekt, F1 löst erst nach Sekunden aus). Dazu kommen der 2-mm-Nachbar `BRAKE Out` (0–48 V im PWM-Takt), der fehlende ESD-Schutz und eine 44 mm lange Bahn am Schaltknoten entlang. Freie GPIOs (D4, D5, D8) gehören, falls je gebraucht, auf die Logikseite, z. B. als Testpad oder DNP-Stiftleiste neben dem XIAO. Namenshinweis: „D5" als Bauteil ist die TVS-Diode, der Pin heißt „GPIO D5".

PTSM nur noch für J1/J2 → 12 Stück für sechs Boards; Kleinmengen über die Phoenix-SAMPLE-Nummer **1701101**, die Suffixe `R44`/`R32` sind Gurtware.

**Flächenbilanz gegenüber dem alten Steckerkonzept** — trotz Klemmen und einem Pol mehr an J12/J10 wird es kleiner:

| | alt | neu | Δ |
| --- | ---: | ---: | ---: |
| J12 / J10 | MR30PW-M 257,5 mm² | WAGO 227 mm² | −31 mm² je Stecker |
| J4 | XT30PW 2+2 250,1 mm² | WAGO 227 mm² | −23 mm² |
| J1 / J2 | Micro-Fit 149,0 mm² | PTSM 54,1 mm² | −95 mm² je Stecker |
| J5 / J3 | JST PH horizontal 76,5 / 59,3 mm² | JST PH **vertikal** 49,0 / 49,0 mm² | −27 / −10 mm² |

Summe über alle sieben Stecker: **1199 → 887 mm²**, also ~310 mm² gespart.

**Alle Klemmen sind Top-Entry** — die Kabel verlassen das Board senkrecht zur Platine. Das bestimmt Einbaulage und Zugentlastungen.

**CAN-Pinreihenfolge der Treiber:** GDS68 und RS05 sind **unterschiedlich** belegt. Ein einmaliger Tausch im Schaltplan hilft daher nicht — die Klemme an J4 wird pro Achse passend verdrahtet. Genau dafür ist der Klemmentyp dort richtig.

**Vertauschen der Klemmen ist gutartig:** An J4, J10 und J12 liegen Pin 3 (GND) und Pin 4 (+48 V) gleich. Motorkabel in J10/J12 → CANH auf +5 V, CANL auf GND. Powerkabel in J4 → +5 V auf CANH, GND auf CANL. Beides legt den Bus lahm, zerstört aber nichts (SN65HVD230 Abs-Max +16 V, PESD12VL2BT klemmt erst ab ~14 V). **Gefährlich ist nur eine umgekehrte Aderreihenfolge** (48 V auf Pin 1): in J10/J12 landen dann 48 V auf der 5-V-Schiene (s. Spannungsdomänen), in J4 48 V auf CANH. Deshalb Aderfarben pro Pin festlegen und jedes Kabel vor dem ersten Einschalten durchmessen.

**Bei den Klemmen beachten:** CAN-Paar bis unmittelbar an die Klemme verdrillt lassen (2–3 cm untwistet, max.); Schirm als kurzes Pigtail mit Aderendhülse; Zugentlastung hinter jeder Klemme (Klemmen haben keine); Bestückungsdruck deutlich beschriften.

---

## Bremsen-Endstufe

**Bremse SteadyWin STW-S035** (gleich in GIM6010 und GIM8108), **stromlos geschlossen** (fail-safe):

| Parameter | Wert |
| --- | --- |
| Nennspannung / -strom | 24 V / 0,64 A (15,4 W) |
| Spulenwiderstand | 34 Ω kalt |
| Haltemoment | 0,80 N·m motorseitig → ~6,4 N·m am Gelenk (8:1) |
| Öffnen / Einfallen | ~35 ms / ~20 ms |

**Eigene Messungen (24 V):** Anzug ab ~10,5 V / ~266 mA, Abfall bei ~2,5 V / ~60 mA, Dauerbetrieb 24 V heiß ~450 mA. Hysterese ~4:1, 15 min bei 24 V → 65 °C ohne Schwellenverschiebung.

**Topologie** (netzlisten-verifiziert):

```
+48V ─┬── F1 (PPTC) ── J3.1 ─── [Bremsspule 34Ω] ── J3.2 ───┬── Q2 Drain
      │                                                     │
      └──────────── D1 (K→+48V vor F1, A→Drain) ────────────┤  Freilauf
                                                            ├── R7 150k ── GPIO D3 (Sense) ── R8 6,8k ── GND
                                                       Q2 Source ── GND
```

**D1-Platzierung (bewusst so gelassen):** Die Kathode hängt am ungesicherten +48 V, nicht zwischen F1 und J3.1. Die Schutzfunktion von F1 hängt davon nicht ab: Liegen dauerhaft 48 V an der Spule (FET durchlegiert), fließt der Strom +48 V → F1 → Spule → Q2 → GND, D1 sperrt dabei, und F1 löst in beiden Varianten gleich aus. Der Unterschied betrifft nur den Freilauf: Hier fließt der Haltestrom auch in der PWM-Aus-Phase durch F1 (dauerhaft ~147 mA statt ~15 mA im Mittel). Mit 30 % von I_hold liegt das weit im grünen Bereich (Tabelle unten), und die ~1 Ω von F1 gegen 34 Ω Spule sind vernachlässigbar.

F1 sitzt bewusst auf der **48-V-Seite**: nur dort liegt auch ein Masseschluss einer der beiden Kabeladern hinter dem Schutz. Hinter der Spule wäre ein Kurzschluss der 48-V-Ader gegen Gehäuse gar nicht begrenzt.

Gate: D0 → U3 74AHCT1G125 (VCC 5 V, OE̅ auf GND, R3 10 k Eingangs-Pulldown) → R2 22 Ω → Q2, R4 10 k Gate-Pulldown. **Default = FET aus = Bremse eingefallen**, auch beim Booten/Reset.

**Economizer:** Anzug 100 % Duty (48 V) für ~150 ms → Halten bei ~10,4 % Duty (= 5 V Mittelwert, ~147 mA, ~0,7 W statt 15 W). Einfallen: PWM = 0.

```
LÖSEN:      PWM 100 %, 100–200 ms  →  PWM ~10,4 % halten  →  danach Motor-Torque
SCHLIESSEN: PWM 0 %  (Anker fällt in ~20 ms)
```

**F1 = Littelfuse 60R050XU** (PPTC, 0,5 A Halte- / 1,0 A Auslösestrom, **60 V**) — Symbol `Device:Polyfuse`, Footprint `R0192:Fuse_Littelfuse_60R050XU` (radial THT, RM 5,1 mm, eigenes STEP-Modell). Die ursprünglich vorgesehene Bourns MF-RHT050-2 ist laut Datenblatt nur für **30 V** spezifiziert und damit an 48 V ungeeignet.

| Betriebsfall | Strom | Verhalten |
| --- | --- | --- |
| Halten | 147 mA = 30 % von I_hold | auch bei 65 °C derated (~0,3 A) noch 2× Marge |
| Anzug | 1,41 A für 150 ms | weit unter der Auslösezeit, geht durch |
| FET durchlegiert | 1,41 A dauerhaft = 2,8× I_hold | trippt im Sekundenbereich — lange vor den ~35 s bis zur Isolationsgrenze der Spule |

Der PTC diskriminiert also über die **Dauer**, nicht über den Strom — Anzugspuls und Fehlerstrom sind gleich groß. **Die 60 V sind die bindende Spec**: gängige SMD-PPTCs sind auf 6–30 V spezifiziert und können an einer 48-V-Schiene beim Auslösen durchzünden. Der PTC-Widerstand (Größenordnung 1 Ω) gegen 34 Ω Spulenwiderstand ist vernachlässigbar.

**Schaltverluste sind unkritisch:** während der PWM-Phase fließen nur 147 mA (nicht 1,41 A), bei ~0,5 µs Flanken sind das ~35 mW bei 10 kHz. Der 74AHCT1G125 reicht, ein Gate-Treiber ist nicht nötig.

**Warum keine TVS/Zener am Schaltknoten:**

- **Parallel zu D1** (Schaltknoten → GND, Durchbruch über der Busspannung) leitet sie im Normalbetrieb nie: D1 klemmt den Drain bei ~48,7 V (mit Regen Clamp höchstens ~50,7 V). Sie schützt nur Q2, falls D1 fehlt oder offen ist, siehe D5 unten.
- **Anstelle von D1** passt sie zwar auf den SMA-Footprint, aber die Halte-PWM funktioniert dann nicht mehr. In jeder Aus-Phase muss der Spulenstrom über die TVS abgebaut werden, die Spule sieht −20 V (68 V − 48 V) statt −0,7 V. Mittlere Spulenspannung bei 10,4 % Duty: 0,104 × 48 V − 0,896 × 20 V ≈ −13 V. Der Strom bricht zusammen und die Bremse fällt ein. Halten ginge erst ab ~37 % Duty, und dann verheizt die TVS dauerhaft ~6 W (68 V × 147 mA × 63 %). Das überlebt keine SMA-TVS, und der Vorteil des Economizers ist weg.
- Schnelleres Einfallen bräuchte eine Zener in Reihe zu D1 **plus** einen zweiten (High-Side-)Schalter, der den Zener-Pfad nur beim Einfallen freigibt. Das ist ein Thema für V2.

**D5: TVS als Q2-Schutz (umgesetzt 2026-09-13, DNP).** Sie nützt nur, wenn D1 fehlt oder offen ist (z. B. Lötfehler). Ohne Freilaufpfad liefe der Drain beim Abschalten über die 100 V von Q2 hinaus.

| | |
| --- | --- |
| Bauteil | **Littelfuse SMAJ58A** (unidirektional), Mouser **576-SMAJ58A** |
| Daten | V_RWM 58 V, V_BR ≥ 64,4 V, V_C 93,6 V bei 4,3 A, 400 W Pulsleistung, DO-214AC |
| Symbol / Footprint | `Diode:SMAJ58A` / `Diode_SMD:D_SMA` mit 3D-Modell `D_SMA.step`, DNP-Attribut gesetzt. Die Pins heißen im KiCad-Symbol `A1`/`A2`; maßgeblich ist die Pad-Nummer: Pad 1 = Kathode (Band im Bestückungsdruck) |
| Anschluss | Pad 1 (Kathode) an `BRAKE Out`, Pad 2 (Anode) an GND, per Netzliste geprüft |
| Platz | senkrecht zwischen D1 und J3/F1 (x 177,7 / y 91,6). Kathode über eine 1,5-mm-Bahn direkt von D1 (Drain-Knoten), Anode über 1,5 mm auf die GND-Via bei 176,5 / 87,1. F1 sitzt dafür jetzt oberhalb (y ≈ 86) |
| Einlöten | Kathodenband nach unten, Richtung D1/Q2 (Pad 1 bei y 93,6) |

**Warum 58 V:** Die Sperrspannung muss über dem Bus inklusive Regen Clamp (~50 V) liegen, die Klemmspannung unter den 100 V von Q2. Ohne D1 kann die Bremse bei 10,4 % Duty nicht halten (s. oben), der Fehler fällt also sofort auf. Die TVS muss dann vor allem die eine Abschaltung aus der Anzugsphase abfangen. Das ist Notfallschutz, kein Dauerbetrieb. Unidirektional reicht, weil der Drain wegen der Body-Diode von Q2 nie unter −0,7 V fällt.

**Einfallzeit mit D1:** Der Strom klingt mit τ = L/R ab, die Bremse fällt bei ~60 mA. Aus dem Haltezustand (147 mA) dauert das t ≈ τ · ln(147/60) ≈ 0,9 τ. Für < 20 ms darf die Spule also bis ~0,78 H haben (R ≈ 35 Ω). Die alte Grenze „~380 mH" galt für 24-V-Dauerbetrieb mit ~450 mA (ln(450/60) ≈ 2). Direkt aus der Anzugsphase (1,41 A) wären es ≈ 3,2 τ, dort also nur bis ~0,22 H. Der Economizer beschleunigt das Einfallen damit deutlich. Einfallzeit beim Bring-up messen.

**Sicherheit:** Die Spule hängt an 48 V — ein Not-Aus, der 48 V trennt (Schütz), lässt alle Bremsen zwangsläufig einfallen. Das ist die Hardware-Zwangsabschaltung; ein reiner Software-Not-Aus reicht nicht. **Aber verzögert:** Nach dem Trennen halten die Buskondensatoren (6 × ~300 µF ≈ 1,8 mF, dazu ggf. die Ausgangskondensatoren des Netzteils) die 48 V noch eine Weile. Solange der ESP32 an 5 V hängt, läuft die Halte-PWM weiter. Die Bremsen fallen erst, wenn die mittlere Spulenspannung unter ~2,5 V sinkt, bei 10,4 % Duty also unter ~24 V Bus. Bei 0,1–0,2 A Restlast dauert das einige hundert Millisekunden, und die Motoren sind in dieser Zeit schon stromlos. Abhilfe (Vorschlag, s. [Not-Aus-Konzept](../doku/estop_konzept.md)): **Die Firmware erkennt den Spannungseinbruch selbst.** Der Sense-Teiler R7/R8 misst in der PWM-**Aus**-Phase die Busspannung, weil der Schaltknoten dann über D1 bzw. die Spule am Bus hängt (48 V → 2,08 V am ADC). Trip-Bedingung `U_bus < 40 V für > 2 ms` → `PWM = 0`, die Bremse fällt in ihren ~20 ms. Kostet keine Hardware und braucht keine CAN-Nachricht vom Pi. Die Alternative „das Schütz trennt auch die 5 V" (dann schalten R3/R4 den FET sofort ab) funktioniert ebenfalls, nimmt aber beim Not-Aus CAN-Bus und Homing-Nodes mit — also genau die Diagnose, die man dann braucht.

Der Sense-Pin ist **Diagnose, keine Schutzfunktion** — er erkennt einen durchlegierten FET, kann ihn aber nicht abschalten. 0 V bei PWM = 0 heißt „FET durchlegiert **oder** Bremsleitung unterbrochen": Beides ist ein Fehler, lässt sich aber nicht unterscheiden.

---

## CAN-Bus: Referenz, Schirm, Terminierung

**Das Kabel ist geklärt.** Das igus-Datenblatt (`.../Kabel/IGUS_DE_Datenblatt_chainflex_CFBUS.PVC.pdf`) listet **CFBUS.PVC.020–.022 explizit unter „CAN-Bus/Feldbus"** mit **Wellenwiderstand 120 ± 12 Ω** (≥ 1 MHz) und 41 pF/m. Der 150-Ω-Profibus-Typ ist `.001` (1×2×0,64). Die eingesetzte **CFBUS.PVC.021 (2×0,5)C ist also ein echtes 120-Ω-CAN-Kabel** — die Terminierung bleibt auf 120 Ω gesamt.

**Warum keine eigene GND_CAN-Ader nötig ist.** Die CAN-Klemmen J1/J2 führen nur H/L/Schirm; die Referenz läuft über die Power-GND aus J10/J12, und zum Motortreiber über J4.3. Beides ist bereits vorhanden — der Treiber hat seine CAN-Masse also über dieselbe Klemme wie CANH/CANL. Eine zusätzliche dünne Ader würde daran nichts ändern:

| Pfad zwischen zwei Boards (0,5 m Hop) | Querschnitt | R |
| --- | --- | ---: |
| vorhandene GND über J10/J12 | 2 × 1,5 mm² = 3 mm² | **~3 mΩ** |
| hypothetische GND_CAN-Ader | 0,25 mm² | ~34 mΩ |

Die neue Ader wäre 12× hochohmiger als die schon vorhandene Verbindung und übernähme parallel nur ~8 % des Stroms — das Bezugspotenzial bestimmt der niederohmigste Pfad. Kaskadiert über sechs Achsen (Hop 1 trägt 6 Motoren, Hop 5 einen):

```
ΔU = R_hop · I_Motor · (5+4+3+2+1) = 3 mΩ · 2 A · 15  ≈  90 mV
absurder Worst Case (12,5 A durch alle Hops):          < 200 mV
```

Gegenüber dem Budget des SN65HVD230 — Betrieb −2 … +7 V, **Absolut-Maximum an CANH/CANL nur −4 … +16 V** (Datenblatt, Transientenpuls über 100 Ω bis ±25 V) — sind das ~10 % vom engsten (negativen) Rand. Faktor 10 Marge, kein Grenzfall.

> **Bedingung dafür**: CAN-Kabel und Powerkabel **im selben Bündel / derselben Schleppkette** führen. Dann liegt die GND-Ader physisch neben dem Paar und die Schleifenfläche bleibt klein. Das ist der eigentliche Wirkhebel, nicht der Aderquerschnitt.

> Falls später doch getrennte Wege nötig werden: **CFBUS.PVC.020, (4×0,25)C, ebenfalls 120 Ω**, OD 7,0 mm statt 8,5 mm — dünner in der Kette, und 0,25 mm² sitzt mittig im PTSM-Fenster (0,14–0,5 mm²) statt wie jetzt am Anschlag.

**Schirm — hybride Auflage.** R6 1 M ‖ C11 100 n je Board: DC-getrennt (keine Schleife für die bis zu 12,5 A Motorrückstrom), HF-gebunden. **R10 (0 Ω, harte Auflage) darf nur auf genau einem Board bestückt werden** — am Pi-/Steuerungsende. Sechs harte Auflagen wären genau die Schleife, die das 1 M vermeiden soll. Gehört in den Bestückungsplan.

**Split-Termination** (statt einem 120-Ω-Widerstand):

```
CANH ──[SW1 Pol A]── R13 60,4Ω ──┬── R12 60,4Ω ──[SW1 Pol B]── CANL
                                 │
                                C13 4,7 nF (C0G)
                                 │
                                GND
```

Das gibt die Common-Mode-Dämpfung und -Referenz, die ohne eigene CAN-GND-Ader sonst fehlt. Eckfrequenz `f_c = 1/(2π · (60‖60) · 4,7 nF) ≈ 1,1 MHz` — passend für 1 Mbit/s (TI/Bosch empfehlen 4,7–10 nF).

- **SW1 muss 2-polig sein** (`Switch:SW_DIP_x02`, bestückt: **CTS 219-2LPSTJ**, Footprint `Button_Switch_SMD:SW_DIP_SPSTx02_Slide_6.7x6.64mm_W6.73mm_P2.54mm_LowProfile_JPin`), je ein Pol pro Zweig. Mit einem 1-poligen Schalter bliebe bei offenem Schalter `CANH → 60 Ω → 4,7 nF → GND` hängen (bei 10 MHz ~63 Ω gegen GND, vier nicht terminierte Boards parallel ~16 Ω) — eine einseitige HF-Last auf CANH und damit genau die Unsymmetrie, gegen die die Split-Termination antritt. Gewählt wurde der CTS 219-2LPSTJ (Raster 2,54 mm, 6,7 × 6,6 mm) statt des kleineren Copal CHS-02 (Raster 1,27 mm), weil er ohne Footprint-Wechsel auf das bestehende Layout passt.
- **60,4 Ω, 1 % (E96)** — nicht 60 Ω (kein E-Reihen-Wert) und nicht 5 %: ungleiche Hälften wandeln Common Mode in Differential Mode um.
- **C13 als C0G/NP0**, nicht X7R (DC-Bias-/Temperaturdrift verschiebt die Eckfrequenz).

**Bus-Schutz.** Bei −4 / +16 V Absolut-Maximum an den Busklemmen und 48 V in derselben WAGO-Klemme wie CANH/CANL (J4) gehört an jedes Board ein **CAN-TVS** (NUP2105L / PESD2CANFD o. ä., SOT-23) am J1/J2-Knoten. *Umgesetzt:* D2 **Nexperia PESD12VL2BT,215**: 12 V V_RWM, V_BR 14,2–16,7 V, 19 pF, 200 W, SOT-23. Pin 1 = CANH, Pin 2 = CANL, Pin 3 = GND (jede Leitung gegen GND, **nicht** CANH–CANL), Symbol `Power_Protection:NUP2105L` mit geändertem Value. Die übliche NUP2105L (24 V, V_BR ≥ 26,2 V) klemmt erst oberhalb der −4/+16-V-Grenze des SN65HVD230. D2 sitzt nicht am J1/J2-Knoten, sondern ~7 mm vor U4 am Ende der Stichleitung (GND-Via direkt daneben). Für den Schutz des Transceivers ist das gleichwertig. Galvanische Isolation (ISO1042 + isolierter DC/DC) wäre bei 6 Knoten und ~2–3 m Bus Overkill.

**Stichleitungen** bei 1 Mbit/s kurz halten: Abzweig J4 → Motortreiber möglichst < 30 cm. Die Gesamtlänge ist unkritisch (1 Mbit/s erlaubt 40 m).

---

## Spannungsdomänen

| Domäne | Quelle | Versorgt |
| --- | --- | --- |
| 48 V | Tether (durchgeschleift) | Motorabzweig, Bremsen-Endstufe |
| 5 V | Tether (durchgeschleift) | TLE4905L, AP2112K-Eingang, U3 (Gate-Treiber) |
| 3,3 V | U1 AP2112K-3.3 (600 mA) | XIAO, SN65HVD230, Pull-up |
| GND | ein gemeinsames Netz | alles |

**Rückspeisung beim Abbremsen:** Das Netzteil kann keinen Strom aufnehmen. Ein zentraler **ODrive Regen Clamp** am Bus begrenzt die Spannung auf ~50 V. Damit bleiben alle Bauteile mit Abstand unter ihren Grenzen: F1 60 V, SMAJ58A (falls bestückt) 58 V Sperrspannung, GDS68 max. 72 V laut Handbuch, Q2 und Elkos 100 V. Die Ausgangsspannung des 48-V-Netzteils muss klar unter der Clamp-Schwelle liegen, sonst arbeitet der Clamp dauerhaft und heizt. **Die Clamp gehört auf die Lastseite des Not-Aus-Schützes** — sonst hat die Rückspeisung nach einem Not-Aus keinen Abfluss mehr (s. [Not-Aus-Konzept](../doku/estop_konzept.md)).

CAN hat keine eigene GND-Ader (J1/J2 führen nur H/L/Schirm) — die Referenz kommt über die durchgehende Power-GND. **Muss über alle Boards durchgängig sein.** Rechnung und Begründung siehe „CAN-Bus: Referenz, Schirm, Terminierung" oben.

**D3 (SMAJ5.0CA, SMA/DO-214AC):** ausgewählt über Sperrspannung und Pulsenergie, **nicht** über den Laststrom — im Normalbetrieb führt sie keinen Strom. Die **CA-Variante ist bidirektional**, damit ist die Einbaurichtung egal (bei der unidirektionalen SMAJ5.0A müsste Pin 1 die Kathode sein, und das Symbol zeigt das nicht an).

Was sie leistet: Transienten und ESD wegstecken, und falls 48 V auf die 5-V-Schiene gelangen, als **Crowbar** in den Kurzschluss gehen und das Netzteil in die Strombegrenzung werfen. Sie klemmt bei ~9,2 V und hält den AP2112K (Abs-Max VIN 6,0 V) bei dauerhafter Überspannung **nicht** am Leben — das ist eine bewusst akzeptierte Grenze.

**Kein Serienelement vor D3 (entschieden 2026-09-13):** Die 5 V laufen als Fläche auf In2 direkt von J10.1 nach J12.1. Ein Serienelement ginge nur mit einem eigenen lokalen 5-V-Netz und Layoutumbau. Stattdessen wird sorgfältig verdrahtet: Aderfarben pro Pin festlegen und jedes Kabel vor dem ersten Einschalten durchmessen (+48 V nur auf Pin 4). Bei umgekehrter Aderreihenfolge liegen 48 V auf der 5-V-Schiene. D3 geht dann als Crowbar in den Kurzschluss und stirbt dabei vermutlich (12,5 A × ~9 V ≈ 112 W). Ob sie kurz oder offen ausfällt, ist Glückssache, und „offen" heißt 48 V auf U1, U3, dem XIAO und dem Hallsensor.

---

## 48-V-Pufferkondensatoren (C2/C3/C14)

Die GDS68 haben kaum eigene Eingangskapazität, und das Board sitzt per M2 direkt am Treiber (kurze J4-Leitung). C2/C3/C14 sind damit praktisch die **Eingangskondensatoren des Treibers**. Ihre Aufgabe ist der Schaltstrom des Wechselrichters (Rippel im PWM-Takt), **nicht** Energie für Beschleunigungen:

```
ΔU = I · t / C
Rippel, ~1 PWM-Periode:   2 A · 40 µs / 300 µF  ≈ 0,3 V     → machbar
Beschleunigung:           5 A · 10 ms / 300 µF  ≈ 167 V     → unmöglich, kommt aus dem Netzteil über die Leitung
```

Mehr µF helfen also kaum. Entscheidend sind **Rippelstrom-Belastbarkeit, Impedanz bei 10–100 kHz und Temperatur** (warmes Gelenkgehäuse).

**Belastung:** GIM6010-8 (48 V): 2,8 A Nennstrom, 17,2 A Blockierstrom. GDS68 laut Handbuch: 6 A Nennstrom, 30 A max. Leitungsstrom. Der Eingangs-Rippelstrom eines 3-Phasen-Wechselrichters liegt grob bei 0,3–0,65 × Phasenstrom, im Nennbetrieb also bei ~1–2 A rms, kurzzeitig deutlich mehr. Pro Elko sind das ~0,3–0,7 A.

| | Nichicon **UVR2A101MPD** (bestellt) | Nichicon **UHE2A820MPD** (Alternative) |
| --- | --- | --- |
| C / U / Maß | 100 µF / 100 V / Ø10 × 20, RM 5 | 82 µF / 100 V / Ø10 × 20, RM 5 → **gleicher Footprint** |
| Serie | Standard („entertainment electronics") | Low Impedance, Long Life |
| Temperatur / Lebensdauer | 85 °C / 2000 h | 105 °C, Long Life |
| tan δ (120 Hz) | 0,08 → ESR ≤ ~1 Ω bei 120 Hz | 0,08 |
| Impedanz 100 kHz | nicht spezifiziert | **0,21 Ω** (20 °C), 0,94 Ω (−10 °C) |
| Rippelstrom | 370 mA (85 °C / 120 Hz), bei ≥ 10 kHz × ~1,5–2 | **518 mA (105 °C / 100 kHz)** |

Quellen: Nichicon-Kataloge UVR und UHE (CAT.8100M).

**Entscheidung (2026-09-13): UVR2A101MPD bleiben.** Die UHE kostet etwa das Doppelte. Für die Belastung reicht die UVR, die UHE wäre nur die robustere Wahl bei dauerhaft hoher Last im warmen Gehäuse.

**Zwei kleinere Elkos statt C14? Lohnt sich nicht.** Innerhalb einer Serie hängt der ESR an der Gesamtkapazität, nicht an der Stückzahl: Bei der UVR ist tan δ für alle 100-V-Werte 0,08, also ist ESR ∝ 1/C. Werte aus dem UVR-Katalog:

| Variante | C gesamt | Rippelstrom gesamt (85 °C / 120 Hz) | Bauhöhe |
| --- | ---: | ---: | ---: |
| 1 × UVR2A101MPD, Ø10 × 20 (jetzt) | 100 µF | 370 mA | 20 mm |
| 2 × UVR2A470MPD, Ø10 × 12,5 | 94 µF | 460 mA | 12,5 mm |
| 2 × UVR2A330MPD, Ø8 × 11,5 | 66 µF | 360 mA | 11,5 mm |

Der ESR bleibt praktisch gleich. Die 47-µF-Variante bringt ~25 % mehr Rippelstrom bei gleichem Durchmesser, die Ø-8-Variante hat weniger Kapazität, also *weniger* Reserve. Einziger echter Vorteil wäre die geringere Bauhöhe. Dafür müsste die dicht belegte Mitte (C14 zwischen C2/C3 und J6) umgeroutet werden. Die wirksamen Hebel liegen woanders:

1. **J4-Adern +48 V/GND kurz und verdrillt** zum Treiber führen: Jeder Zentimeter Schleifenfläche liegt zwischen Elko und Brücke.
2. *Am Treiber:* Hat der GDS68 an den Leistungs-MOSFETs gar keine Keramikkondensatoren, 1–2 × MLCC 2,2–4,7 µF / 100 V (X7R, 1210) direkt an seinen Versorgungspads nachrüsten. Die MHz-Anteile der Schaltflanken kann nur ein Kondensator unmittelbar an der Brücke liefern, nicht das Board über die Leitung.
3. **Keine Polymer- oder Ultra-Low-ESR-Kondensatoren** auf dem Bus: Mit der Leitungsinduktivität zwischen den Boards bilden sie einen kaum gedämpften Schwingkreis, und beim Zuschalten schwingt die Spannung auf bis zu ~2× über. Der ESR der Alu-Elkos dämpft das.
4. 48 V nie unter Spannung stecken, sondern zentral schalten (Schütz/Netzteil).

---

## Stückliste (BOM) — Bestellstand 2026-09-11

Bezeichner laut Schaltplan-BOM, Mengen für **6 Boards** plus Reserve. Bezugsquellen: Mouser-Projekte `R0192` und `R0192_Kleine_Komponenten`, WAGO/Netzteil/Crimpzange bei Reichelt.

### Kondensatoren

| Ref | Wert | Hersteller | Herst.-Nr. | Bestell-Nr. | je Board | bestellt |
| --- | --- | --- | --- | --- | ---: | ---: |
| C1, C7, C9, C11, C12 | 100 nF 50 V X7R 0603 | Yageo | CC0603KPX7R9BB104 | Mouser 603-CC603KPX7R9BB104 | 5 | 35 |
| C4 | 100 nF **100 V** X7R 0805 | Yageo | CC0805KKX7R0BB104 | Mouser 603-CC805KKX7R0BB104 | 1 | 10 |
| C5 | 1 µF 25 V X5R 0603 | Samsung | CL10A105KA8NFNC | Mouser 187-CL10A105KA8NFNC | 1 | 10 |
| C6 | 2,2 µF 16 V X5R 0603 | Samsung | CL10A225KO8NNNC | Mouser 187-CL10A225KO8NNNC | 1 | 10 |
| C8 | 10 µF 25 V X5R 0805 | Samsung | CL21A106KAYNNNG | Mouser 187-CL21A106KAYNNNG | 1 | 10 |
| C10 | 1 nF 50 V **C0G** 0603 | Murata | GRM1885C1H102JA01D | Mouser 81-GRM39C102J50 | 1 | 10 |
| C13 | 4,7 nF 50 V **C0G** 0603 | Murata | GRM1885C1H472JA01D | Mouser 81-GRM1885C1H472JA1D | 1 | 10 |
| C2, C3, C14 | 100 µF **100 V** Elko, Ø10 × 20 mm, RM 5 | Nichicon | UVR2A101MPD1TD | Mouser 647-UVR2A101MPD1TO | 3 | 15 (**für 6 Boards 18 nötig, 3+ nachbestellen**) |

### Widerstände (Yageo RC0603, 1 %, 1/10 W)

| Ref | Wert | Herst.-Nr. | Bestell-Nr. | je Board | bestellt |
| --- | --- | --- | --- | ---: | ---: |
| R1 | 4,7 kΩ | RC0603FR-074K7L | Mouser 603-RC0603FR-074K7L | 1 | 10 |
| R2 | 22 Ω | RC0603FR-1322RL | Mouser 603-RC0603FR-1322RL | 1 | 10 |
| R3, R4 | 10 kΩ | RC0603FR-0710KL | Mouser 603-RC0603FR-0710KL | 2 | 15 |
| R5, R14 | 220 Ω (UART-Serienwiderstände J6) | RC0603FR-07220RL | Mouser 603-RC0603FR-07220RL | 2 | 15 |
| R6 | 1 MΩ | RC0603FR-071ML | Mouser 603-RC0603FR-071ML | 1 | 10 |
| R7 | 150 kΩ | RC0603FR-07150KL | Mouser 603-RC0603FR-07150KL | 1 | 10 |
| R8, R9 | 6,8 kΩ | RC0603FR-076K8L | Mouser 603-RC0603FR-076K8L | 2 | 15 |
| R10 | 0 Ω (5 %), **nur auf einem Board** (Steuerungsende) | RC0603JR-070RL | Mouser 603-RC0603JR-070RL | 0–1 | 10 |
| R11 | 470 Ω | RC0603FR-07470RL | Mouser 603-RC0603FR-07470RL | 1 | 10 |
| R12, R13 | 60,4 Ω | RC0603FR-0760R4L | Mouser 603-RC0603FR-0760R4L | 2 | 15 |

### Halbleiter, Schutz, Schalter

| Ref | Funktion | Hersteller | Herst.-Nr. | Bestell-Nr. | je Board | bestellt |
| --- | --- | --- | --- | --- | ---: | ---: |
| D1 | Freilaufdiode, ultrafast 200 V / 1 A, SMA | Diotec | US1D | Mouser 637-US1D | 1 | 10 |
| D3 | TVS 5 V bidirektional, SMA | Littelfuse | SMAJ5.0CA | Mouser 576-SMAJ5.0CA | 1 | 10 |
| D4 | Status-LED rot, 0603 | Lite-On | LTST-C191KRKT | Mouser 859-LTST-C191KRKT | 1 | 10 |
| Q2 | N-MOSFET 100 V, 0,125 Ω @ V_GS 5 V, TO-252 | Infineon | IRLR3410TRPBF | Mouser 942-IRLR3410TRPBF | 1 | 10 |
| U1 | LDO 3,3 V / 600 mA, SOT-23-5 | Diodes Inc. | AP2112K-3.3TRG1 | Mouser 621-AP2112K-3.3TRG1 | 1 | 10 |
| U2 | XIAO ESP32-S3 (Stiftleisten lose beiliegend) | Seeed Studio | 113991114 | Mouser 713-113991114 | 1 | 6 |
| U3 | Puffer 74AHCT1G125, SOT-25 | Diodes Inc. | 74AHCT1G125QW5-7 | Mouser 621-74AHCT1G125QW5-7 | 1 | 10 |
| U4 | CAN-Transceiver 3,3 V, SOIC-8 | Texas Instruments | SN65HVD230DR | Mouser 595-SN65HVD230DR | 1 | 10 |
| F1 | PPTC **60 V**, 0,5 A hold / 1 A trip, radial RM 5,1 | Littelfuse | 60R050XU | Mouser 576-60R050XU | 1 | 10 |
| SW1 | Split-Termination, DIP 2-polig, Low Profile, J-Bend | CTS | 219-2LPSTJ | Mouser 774-219-2LPSTJ | 1 | 10 |
| SW2 | 3,3-V-Trennung zum XIAO, Schiebeschalter SPDT 300 mA | C&K | PCM12SMTR | Mouser 611-PCM12SMTR | 1 | 7 |
| D2 | CAN-TVS 12 V, 2 Leitungen bidirektional gegen GND, SOT-23 | Nexperia | PESD12VL2BT,215 | Mouser 771-PESD12VL2BT215 | 1 | **noch bestellen** |
| D5 (DNP) | TVS 58 V unidirektional, Q2-Schutz bei fehlendem D1, SMA | Littelfuse | SMAJ58A | Mouser 576-SMAJ58A | 0 (DNP) | **noch bestellen** (Reserve) |

### Steckverbinder (Platine)

| Ref | Funktion | Hersteller | Herst.-Nr. | Bestell-Nr. | je Board | bestellt |
| --- | --- | --- | --- | --- | ---: | ---: |
| J1, J2 | CAN-Bus, Push-in 3-polig, RM 2,5 | Phoenix Contact | PTSM 0,5/3-2,5-V THR R44 (1770966) | Mouser 651-1770966 | 2 | 15 |
| J3, J5 | Bremse / Hallsensor, JST PH 3-polig vertikal | JST | B3B-PH-K-S-GW | Mouser 306-B3BPHKSGW | 2 | 15 |
| J4, J10, J12 | Motorabzweig / Power, Hebelklemme 4-polig, RM 3,5 | WAGO | 2601-3104 | Reichelt WAGO 2601-3104 | 3 | 20 |
| J6 | UART-Debug, Stiftleiste 1×4, RM 2,54 | Würth Elektronik | 61300411121 | Mouser 710-61300411121 | 1 | 10 |

### Kabelseite & Werkzeug (nicht auf der Platine)

| Teil | Verwendung | Hersteller | Herst.-Nr. | Bestell-Nr. | bestellt |
| --- | --- | --- | --- | --- | ---: |
| PH-Gehäuse 3-polig | Gegenstecker J3 / J5 | JST | PHR-3 | Mouser 306-PHR-3 | 15 |
| PH-Crimpkontakt AWG 30–24 | J3 (2 Pins) + J5 (3 Pins) | JST | SPH-002T-P0.5S | Mouser 306-SPH-002T-P0.5S | 100 |
| Aderendhülse unisoliert 0,5 mm² × 6 mm | J1 / J2 (CAN + Schirm-Pigtail) | Altech | 2216.0 (H0.50/6) | Mouser 845-2216.0 | 50 |
| Aderendhülse unisoliert 1,5 mm² × 10 mm | J4 / J10 / J12 Power-Adern | Altech | 2222.0 | Mouser 845-2222.0 | 100 |
| Crimpzange Aderendhülsen 0,25–6 mm² | Aderendhülsen | — | CRIMPZANGE AEH | Reichelt | 1 |
| 5-V-Netzteil 90 W / 18 A | 5-V-Schiene (einmal pro Arm) | MEAN WELL | LRS-100-5 | Reichelt MW LRS-100-5 | 1 |

**Bereits vorhanden:** Hallsensoren TLE49x5L und Magnete Ø 4 × 2 mm (Reichelt MAGNET 4.2). **Typ prüfen:** Homing-Ablauf und Firmware setzen einen **TLE4905L** (unipolarer Schalter) voraus; ein **TLE4935L** (bipolarer Latch) gibt mit nur einem Magneten nach dem Überfahren nicht wieder frei.

**Hinweise zur BOM**

- **Aderendhülsen:** Die WAGO 2601 ist für 8–9 mm Abisolierlänge ausgelegt; steht die 10-mm-Hülse sichtbar über das Gehäuse, nach dem Crimpen auf ~8 mm kürzen. Die CAN-Adern in **J4 ohne Hülse** klemmen (0,5 × 6 mm ist dort zu kurz; feindrähtig ohne Hülse ist zulässig). Isolierte Hülsen passen nicht: WAGO nimmt isolierte Hülsen nur bis 0,75 mm², PTSM gar nicht.
- **Altech 2222.0:** Mouser beschreibt sie als „H100/10“; nach Altech-Nummernschema (2219/2220 = 1,0 mm², 2221/2222 = 1,5 mm²) ist es die 1,5-mm²-Hülse — beim Auspacken kurz gegenprüfen.
- **Nicht bestellt / nicht nötig:** Buchsenleisten für den XIAO (wird direkt gelötet), Serien-PTC in der 5-V-Einspeisung (bewusst verworfen, s. Spannungsdomänen).

---

## Layout-Stand (geprüft 2026-09-13)

Geprüft mit `kicad-cli` (ERC; DRC mit Schaltplan-Parität und neu gefüllten Zonen) und einer Widerstandsrechnung der In2-Flächen (Gitter 0,1 mm auf den gefüllten Zonenpolygonen aus pcbnew).

**DRC:** 0 unverbundene Pads, 0 Footprint- und Paritätsfehler. Übrig bleiben 6× Silk-Überlappung C2/C14, 6× Silk am Platinenrand (J10/J12/U2-USB), 1× Texthöhe 0,7 mm („USB-C") und 2× Courtyard H3↔J12 / H4↔J10. Bei den Courtyards Schraubenkopf und Unterlegscheibe gegen das WAGO-Gehäuse mechanisch prüfen.

**Lagen:** F.Cu Signale · In1 GND (eine durchgehende Fläche) · In2 +48 V mit eingeschnittener +5-V-Fläche · B.Cu GND + 3,3-V-Insel + wenige Signale. Im KiCad-Stackup stehen alle Lagen auf 35 µm. **Innenlagen-Kupfer beim Fertiger prüfen**, viele Standard-4-Lagen-Aufbauten haben innen 0,5 oz. Die Rechnung unten deckt beide Fälle ab.

**48 V auf In2 — nachgerechnet:**

| Pfad | R (35 µm) | R (17,5 µm) | Verlust bei 12,5 A (17,5 µm) | engste Stelle (äquiv. Breite) |
| --- | ---: | ---: | ---: | ---: |
| J10.4 → J12.4 | 1,2 mΩ | 2,5 mΩ | ~0,38 W | ~5 mm |
| J10.4 → J4.4 | 1,1 mΩ | 2,2 mΩ | ~0,34 W | ~6 mm |
| J12.4 → J4.4 | 1,3 mΩ | 2,6 mΩ | ~0,40 W | ~5,5 mm |
| +5 V: J10.1 → J12.1 | 3,0 mΩ | 6,1 mΩ | bei ~1 A: ~6 mW | ~2 mm |

Die alte Vorgabe hier („In2 bräuchte ~25 mm Breite") kam aus der IPC-2221-Leiterbahnformel. Die gilt für lange, isolierte Bahnen und ist für eine ganze Lage viel zu konservativ: Die Verluste verteilen sich über ~2500 mm². Die Stromdichte-Spitzen (~2,5 A/mm bei 12,5 A) liegen nur lokal an der unteren Ecke des 5-V-Stegs zwischen J10 und J12 (≈ x 150 / y 82) und an den Pad-Kanten. **48 V ausschließlich auf In2 ist damit in Ordnung, auch bei 0,5 oz.** Optionale Verbesserung: Den 5-V-Steg zwischen J10.1 und J12.1 als ~2-mm-Bahn auf F.Cu oder B.Cu führen. Dann läuft der 48-V-Pfad J10→J12 ohne Umweg.

**Umgesetzt:**

- GND: In1 vollflächig plus B.Cu-Pour. Ein gemeinsamer GND statt Sternpunkt ist bei dieser Größe mit durchgehender Innenlage die bessere Lösung.
- Bremsen-Schaltknoten klein (Q2 / D1 / J3 / F1 eng beieinander). Brems-PWM liegt rechts, CAN links: Das Trennkonzept ist im Layout eingehalten.
- THT-Pads von J10/J12/J4 massiv angebunden (Custom-Rule `Power-Klemmen massiv an Flaechen` in `.kicad_dru`), kein Lagenwechsel im 48-V- und GND-Pfad.
- Bremskanal 1,5 mm auf F.Cu (≥ 2 A).
- D5 (SMAJ58A, DNP) zwischen D1 und J3 ergänzt, F1 dafür nach oben verschoben. `BRAKE +48V` läuft als 1,5-mm-Bahn rechts an D5 vorbei zu J3.1.
- D3 direkt an J12.1, wo die 5 V ankommen.
- 48-V-Clearance 0,5 mm (Netclass `HV_Bus_48V` und Zonen), DRC-Minima eingetragen (Clearance und Track 0,15 mm). Nachgeprüft: Alle 48-V-führenden Netze haben außen ≥ 0,5 mm, auch die Bremsnetze. Die Netzklassen `CAN`/`HV_Brake` haben kein Pattern mehr, das Layout hält die Abstände aber ohnehin ein. Einordnung nach IPC-2221B für 31–50 V: innen (B1) 0,1 mm, außen unbeschichtet (B2) 0,6 mm, außen mit Polymerbeschichtung (B4) 0,13 mm. 0,5 mm mit Lötstopplack ist ok.
- PCB synchron zum Schaltplan (DRC-Parität sauber), In2-Zonen vorhanden, In1-Zone deckt die ganze Platine ab, keine entarteten Punkte mehr auf Edge.Cuts.
- Platinenumriss: Kreis Ø 70 mm (Mitte 150/100) mit Abflachungen → 66,05 × 64 mm, 4× M2.
- C2/C3/C14 als `Device:C_Polarized` (Polaritätsmarkierung im Bestückungsdruck, auf dem Board gibt es keinen Verpolschutz). 3D-Modell: KiCad hat Ø 10 × 20 mm nur mit RM 7,5, daher Footprint `CP_Radial_D10.0mm_P5.00mm` mit **Scale Z = 2,0** (per Render geprüft).

---

## Fertigung

**Gewählt: JLCPCB.** Für ein 4-Lagen-Board unter 100 × 100 mm ist das der günstigste Weg. Bis 150 € Warenwert zieht JLCPCB die Einfuhrumsatzsteuer schon beim Bestellen ein (IOSS), bei DHL fallen also keine Zollgebühren an. Alternativen: **AISLER** (Aachen, Fertigung in Europa, kein Import, dafür teurer) und **PCBWay** (ähnlich wie JLCPCB).

**Bestellkonfiguration PCB (Stand 2026-09-15, Angebot 39,94 € + 23,24 € DHL Express):**

| Option | Gewählt | Anmerkung |
| --- | --- | --- |
| Material / Lagen / Dicke | FR-4 TG135, 4 Lagen, 1,6 mm | JLCPCB erkennt 66,05 × 64 mm |
| Menge | 10, Single PCB | das Minimum von 5 reicht nicht für 6 Boards |
| Farbe / Druck | grün / weiß | |
| Oberfläche | HASL bleifrei | passt zu Handlöten und Heizplatte, feinstes Raster ist SOIC 1,27 mm |
| Kupfer außen / innen | 1 oz / **1 oz** (+14,51 €) | 0,5 oz würde laut Rechnung im Layout-Stand reichen. 1 oz halbiert den Widerstand der 48-V-Fläche (J10→J12 ≈ 1,2 statt 2,5 mΩ). Bewusst als Reserve gewählt, weil der gesamte Busstrom auf In2 läuft |
| Lagenreihenfolge festlegen | **Ja** | L1 `DriverDasyChain-F_Cu.gbr`, L2 `-GND.gbr`, L3 `-PWR.gbr`, L4 `-B_Cu.gbr`. Damit ist kein Neuexport mit Protel-Endungen nötig |
| Stackup festlegen | Nein | Standard-Stackup, keine Impedanzkontrolle nötig |
| Via-Abdeckung | Plugged | passt zum Tenting im KiCad-Stackup, beim Reflow läuft kein Lot in die Vias |
| Min. Via | 0,3 mm / (0,4/0,45 mm) | kleinste Via im Design: 0,3 mm Bohrung, 0,6 mm Pad |
| Produktionsdatei bestätigen | *Empfehlung: Ja* | beim ersten 4-Lagen-Auftrag die Lagenzuordnung vor der Fertigung freigeben. Prüfen, ob sich der Preis ändert |
| Markierung | Remove Mark | keine Auftragsnummer im Bestückungsdruck |
| Elektrischer Test | Flying Probe | |
| Fertigungszeit | 3–4 Tage | |

**Schablone (zusammen mit dem PCB):**

| Option | Gewählt | Anmerkung |
| --- | --- | --- |
| Framework | **Nein** | Die Rahmenschablone 470 × 370 mm wiegt allein 1,5 kg und ist für Schablonendrucker gedacht. Für die Heizplatte reicht eine rahmenlose Schablone in der kleinsten Größe, die das Board mit Rand abdeckt |
| Stufen-Schablone / Nano-Coating | Nein | |
| Seite | Top only | alle SMD-Teile sitzen oben |
| Dicke | durch JLCPCB (üblich 0,12 mm) | passt für 0603, SOT-23, SOIC, SMA und TO-252 |
| Prozess / Politur | Lotpasten-Schablone / Sanding | |
| Fiducials | keine | das Board hat keine |
| Öffnungen | JLCPCB-Standard | Die Pasten-Lage enthält auch die DNP-Pads von D5 und R10. Diese Öffnungen vor dem Rakeln mit Kapton abkleben, das ist einfacher als eine Sonderanfrage |

**Export aus KiCad:**

1. Zonen neu füllen (`B`), DRC laufen lassen.
2. *Datei → Fertigungsunterlagen → Gerber:* F.Cu, GND (In1), PWR (In2), B.Cu, F.Mask, B.Mask, F.Silkscreen, B.Silkscreen, Edge.Cuts. Unter Optionen „Zonenfüllungen vor dem Plotten prüfen", „Erweitertes X2-Format" und „Netzlisten-Attribute" anhaken. „Protel-Dateiendungen verwenden" ist optional: ohne sie die Lagenreihenfolge bei JLCPCB von Hand zuordnen (so beim Auftrag vom 2026-09-15). Danach *Bohrdateien erzeugen* (Excellon, mm, Nullen „Dezimal", alternativer Bohrmodus für ovale Löcher).
3. Die Dateien am besten **im Terminal** zippen, damit keine macOS-Metadaten mitkommen: `cd PCB/KiCad/Fertigunsunterlagen && rm -f R0192.zip && zip -X R0192.zip *.gbr *.drl *.gbrjob`. Hochladen und im Gerber-Viewer des Fertigers alle vier Kupferlagen in der richtigen Reihenfolge, die Bohrungen und den Umriss prüfen.

**Stand der Fertigungsunterlagen (geprüft 2026-09-15):**

- **Inhalt aktuell:** Die Gerber vom 13.09. 22:30 sind geometrisch identisch mit dem aktuellen PCB (alle Lagen, Flächen, Masken, Paste, Silkscreen), auch mit frisch gefüllten Zonen. Die Bohrdaten sind identisch.
- **Bohrdaten passen zu den Bauteilen:**

  | Bohrung | Anzahl | Verwendung |
  | --- | ---: | --- |
  | 0,3 / 0,4 / 0,6 mm | 24 / 6 / 5 | Vias |
  | 0,75 mm | 6 | JST PH J3/J5 |
  | 0,8 mm | 2 | F1 (Draht 0,51 mm) |
  | 1,0 mm | 24 | XIAO (14), J6 (4), Elkos (6, Draht 0,6 mm) |
  | 1,2 mm | 36 | WAGO (24, laut WAGO-Datenblatt 1,2 (+0,1) mm bei Lötstift 1 × 0,5 mm) und PTSM (12) |
  | 2,2 mm | 4 | M2-Befestigungslöcher |
  | 0,9 mm NPTH | 2 | Positionierstifte SW2 |

  XIAO-Reihenabstand 15,24 mm (6 × 2,54 mm) passt zum Modul.
- **Innenlagen-Dateinamen:** Die Innenlagen heißen `-GND.gbr` / `-PWR.gbr`, weil Protel-Endungen ausgeschaltet sind. Gelöst über „Specify Layer Sequence" bei JLCPCB (L2 = GND, L3 = PWR). Das deckt sich mit den X2-Attributen und der Job-Datei. `R0192.zip` enthält zusätzlich `__MACOSX/._*`-Dateien aus dem Finder; JLCPCB hat die Gerber trotzdem richtig erkannt.
- **Pasten-Lage:** Sie enthält auch die DNP-Pads von D5 und R10. Die Schablonenöffnungen dort abkleben (s. „Bestückung").

---

## Bestückung (selbst löten)

**Strategie (entschieden 2026-09-15):** Board 1 komplett von Hand löten und dabei Block für Block in Betrieb nehmen. Boards 2–6 mit Schablone und Heizplatte. Board 1 dient zum Lernen und zeigt Fehler dort, wo sie entstehen; die restlichen fünf gehen dann schnell.

Umfang pro Board: 34 SMD-Teile mit 93 Lötstellen (alle auf der Oberseite) und 13 THT-Teile mit 68 Lötstellen. Vorhandene Lötstation: Atten ST-909 (90 W). Sie reicht auch für GND-Pads an den Innenlagen.

**Board 1: von Hand, Block für Block**

| Schritt | Bauteile | Test |
| --- | --- | --- |
| 1 Versorgung | J10, D3, C5, C8, U1, C6 | 5 V über J10 mit Strombegrenzung (~100 mA) einspeisen, 3,3 V messen |
| 2 MCU | SW2 (vorher durchpiepen), J6, R5, R14, R11, D4, XIAO | flashen, LED blinken lassen |
| 3 CAN | U4, C7, D2, R12, R13, C13, SW1, R6, C11, J1, J2, J4 | CAN-Test gegen den Pi |
| 4 Hall | C1, R1, R9, C10, J5 | Pegelwechsel mit Magnet |
| 5 Bremse | U3, C9, R2, R3, R4, Q2, D1, R7, R8, C12, C4, F1, J3, C2/C3/C14, J12 | 48 V zuerst mit strombegrenztem Netzteil, dann Anzug, Halten, Einfallzeit |

Innerhalb eines Schritts erst flache, dann hohe Teile: 0603 → SOT/SOIC → SMA/TO-252 → THT.

**Boards 2–6: Schablone und Heizplatte**

1. Platine in eine Halterung legen, z. B. einen 1,6 mm dicken 3D-gedruckten Rahmen mit rundem Ausschnitt oder Reste-Platinen gleicher Dicke drumherum. Die Schablone an einer Kante mit Klebeband anschlagen, damit sie wie ein Scharnier immer gleich liegt.
2. Die Öffnungen von D5 und R10 mit Kapton abkleben.
3. Paste mit einer Karte in einem Zug abziehen, Schablone gerade abheben.
4. SMD-Teile mit der Pinzette setzen.
5. Auf die Heizplatte legen, bis das Lot zusammenläuft, kurz auf Spitzentemperatur halten, dann herunternehmen und abkühlen lassen.
6. Mit Lupe prüfen, Brücken mit Flussmittel und Entlötlitze entfernen.
7. THT von Hand: WAGO, PTSM, JST, J6, Elkos, F1 und XIAO. Sie dürfen **nicht** auf die Heizplatte (Kunststoff, Elkos).

SW1 (CTS 219) und SW2 (PCM12) sind reflowfähige SMD-Teile. Nur kurz auf Spitzentemperatur halten oder vorsichtshalber nachträglich von Hand löten.

**Einkauf**

| Teil | Hinweis |
| --- | --- |
| Schablone | mit dem PCB bei JLCPCB, rahmenlos (s. „Fertigung") |
| Heizplatte | beheizte Fläche **≥ 100 × 100 mm** (Platine 66 × 64 mm), Temperatur einstellbar. Mini-Platten mit 30 × 30 oder 50 × 50 mm sind zu klein |
| Lötpaste | **Sn63Pb37** (183 °C, einsteigerfreundlich) oder **SAC305** (~217 °C, bleifrei, braucht mehr Hitze). Dose zum Rakeln, im Kühlschrank lagern. **Keine Sn42Bi58:** spröde, und der Arm vibriert |
| Lötdraht | gleiche Legierung wie die Paste, ~0,5 mm mit Flussmittelkern |
| Zubehör | No-Clean-Gelflussmittel, feine gebogene Pinzette, Entlötlitze, Isopropanol, Kapton-Band, Lupe oder Mikroskop, Absaugung oder offenes Fenster, strombegrenztes Labornetzteil für die ersten Tests |

**Zeitaufwand (grob)**

| Variante | Board 1 | Boards 2–6 | SMD gesamt |
| --- | --- | --- | --- |
| Alles von Hand | 2–3 h (inkl. Testen) | je 1,5–2 h | ~10–13 h |
| Board 1 von Hand, dann Heizplatte | 2–3 h | je ~30 min + einmal Einrichten | ~5–6 h |

THT kostet in beiden Varianten ~20–30 min pro Board.

---

## Offene Punkte

Stand 2026-09-15: ERC 0 Fehler / 1 Warnung (Bibliothekspfad), DRC 0 offene Pads (nur Silk-/Courtyard-Meldungen). Notiztexte, Values (D4), Notes (C2/C3/C4/C14/J4) und die DNP-Attribute von R10 und D5 sind aktuell. Erledigte Punkte sind gelöscht, ihre Begründungen stehen in den Abschnitten oben.

**Schaltplan / Layout**

- [ ] **ERC-Warnung Bibliothekspfad:** `sym-lib-table` zeigt für `Seeed_Studio_XIAO_Series` noch auf den alten OneDrive-Pfad. Harmlos, weil das Symbol im Schaltplan eingebettet ist. Sauber wäre, die `.kicad_sym` ins Repo zu legen (neben `R0192.pretty`) und per `${KIPRJMOD}` einzubinden.

**Auslegung / Entscheidungen**

- [ ] **Not-Aus-Verzögerung der Bremsen:** Nach dem Trennen der 48 V halten die Buskondensatoren die Bremsen noch einige hundert Millisekunden offen (s. „Sicherheit" im Bremsen-Abschnitt). Vorgeschlagener Weg: Bus-Unterspannung auf dem vorhandenen Sense-Pin D3 erkennen und PWM = 0 setzen — umsetzen und beim Bring-up gegen die reale Einfallzeit messen. Gesamtkonzept in [doku/estop_konzept.md](../doku/estop_konzept.md).
- [ ] **48 V nie unter Spannung stecken** (~1,8 mF Buskapazität, Überschwingen durch Leitungsinduktivität). Zentral am Netzteil bzw. über das Schütz schalten; eine Inrush-Begrenzung gehört, falls überhaupt, dorthin und nicht auf jedes Board. Ausgelegt ist sie als Vorladung (47 Ω, τ ≈ 85 ms) im [Not-Aus-Konzept](../doku/estop_konzept.md).
- [ ] Haltemoment unter Payload an **Achse 2/3** verifizieren (~6,4 N·m Bremse vs. 7,5 N·m Motor-Nennmoment), kalt und warm.
- [ ] Im Bestückungsplan festhalten: **R10 bleibt DNP** (bei Bedarf von Hand am Steuerungsende nachlöten, nie auf mehreren Boards), Split-Termination nur an den zwei Busenden.

**Bestellung**

- [ ] Mouser: D2 PESD12VL2BT,215 (771-PESD12VL2BT215), 6 Stück + Reserve, und D5 SMAJ58A (576-SMAJ58A), einige als Reserve.
- [ ] 3+ UVR2A101MPD nachbestellen (für 6 Boards sind 18 nötig, 15 bestellt).
- [ ] PCB und rahmenlose Schablone bei JLCPCB bestellen. Die Konfiguration steht, die Lagenreihenfolge ist von Hand zugeordnet (s. „Fertigung"). Vor dem Bestellen im Gerber-Viewer die vier Kupferlagen kontrollieren.
- [ ] Bestückungswerkzeug (s. „Bestückung"): Heizplatte ≥ 100 × 100 mm, Lötpaste Sn63Pb37 oder SAC305, Flussmittel, Pinzette, Entlötlitze, Kapton-Band, Isopropanol.

**Bring-up**

- [ ] **Board 1 schrittweise** von Hand bestücken und testen (s. „Bestückung", Schritte 1–5), erst danach Boards 2–6 mit Schablone und Heizplatte.
- [ ] **Vor dem ersten Einschalten jedes Kabel durchmessen:** An J10/J12 darf +48 V nur auf Pin 4 liegen. Es gibt kein Serienelement vor D3 (s. Spannungsdomänen).
- [ ] Kurzschlusstest 48 V / 5 V / 3,3 V gegen GND, 3,3-V-Schiene messen
- [ ] SW2 vor dem Einlöten des XIAO durchpiepen: In Stellung „3.3V" muss XIAO-Pad 12 (3V3) mit J6 Pin 4 (+3,3 V) verbunden sein, in „OFF" nicht.
- [ ] ESP32 flashen, CAN-Loopback, dann `/homing`-Protokoll end-to-end gegen den Pi
- [ ] TLE4905L mit Magnet: sauberer 3,3-V-Pegelwechsel an D1
- [ ] Bremse: Anzug (48 V, 150 ms) → öffnet; Halten bei 10,4 % Duty; **Einfallzeit aus dem Haltezustand messen** (Ziel < 20 ms, entspricht L ≤ ~0,78 H, s. „Einfallzeit mit D1")
- [ ] CAN mit allen 6 Boards bei 1 Mbit/s: Terminierung nur an den Enden, Eye/Fehlerzähler unter laufenden Motoren prüfen (das ist der Test, der die GND-Referenz wirklich beantwortet)

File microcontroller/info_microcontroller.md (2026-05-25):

Hier ist der Code für die Homingsequenz abgelegt. Dieser läuft auf einem Microcontroller. Dieser ist zurzeit ein Arduino Uno R3 (zum Testen) und soll nachher umgerüstet werden auf einen Seeed Studio Xioa ESP32-S3. 

Der Microcontroller soll von dem Hallsensor (TEL4905L) ein Signal bekommen, wenn der an der Achse bewächstigete Magent vorbeifährt und das Magentfeld ändert --> TEL4905L == LOW --> Microcontroller gibt das Signal weiter über Canbus

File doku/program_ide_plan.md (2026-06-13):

# R0192 Program Executor & RViz IDE — Implementierungsplan

## Kontext & Ziel

Erweiterung des bestehenden R0192-ROS2-Projekts um eine industriell-typische Trennung zwischen **Engineering** (Programmieren auf dem PC) und **Operations** (Bedienen am Roboter):

- **VS Code als Engineering-Tool**: Programme werden dort geschrieben/editiert — YAML mit JSON-Schema-Validierung, Autocomplete, Git-Integration.
- **RViz-Panel als Operator-/Runtime-Interface**: Programm laden, starten, pausieren, stoppen, Override, aktuelle Programmzeile anzeigen, Status-Monitoring.

Dieses Modell entspricht der etablierten Aufteilung in der industriellen Robotik (KUKA WorkVisual + SmartPAD, ABB RobotStudio + FlexPendant, Fanuc Roboguide + iPendant) und ist deutlich pragmatischer, als einen vollständigen Programmeditor in RViz nachzubauen.

## Architektur-Prinzipien (nicht verhandelbar)

1. **Trennung Backend / UI / Editor**: Backend (Executor) ist die einzige Stelle mit Geschäftslogik. RViz-Panel = Runtime-Client. VS Code = Editor. Kommunikation nur über ROS 2 Actions/Services und Dateien (YAML).
2. **State-Management nur über `/set_robot_state`**: Programmausführung läuft im `MOVEIT`-State, am Ende immer zurück nach `HOLD`. Niemals direkt `/robot_enable`, `/homing`, `pause_servo` oder Controller-Switch aufrufen.
3. **MoveIt sequenziell für v1**: `MoveGroupInterface` step-by-step. Pilz Industrial Motion Planner kommt erst in einer späteren Phase. *(Update: in Phase 7 umgesetzt — `ptp`/`lin`/`circ` über Pilz, plus Blend-Modus via `/sequence_move_group`. Der sequenzielle `MoveGroupInterface`-Pfad bleibt für „stop at each point" erhalten.)*
4. **Punkte vs. Programme getrennt**: Programme referenzieren Punkte per Name aus einer separaten Punktdatei — keine inline-Posen in Schritten.
5. **Programme sind YAML, kein Custom-DSL**: Files sind menschen- und maschinenlesbar, git-diff-bar und ohne Spezialtools editierbar.

## Rollenverteilung der Tools

| Tool | Rolle | Aufgaben |
| --- | --- | --- |
| **VS Code** | Engineering | Programme schreiben/editieren, Punktnamen referenzieren, Git, Review  |
| **RViz Run-Panel**  | Operator / Runtime  | Laden, Run/Pause/Stop, aktuelle Zeile, Override, Status, Notaus |
| **RViz Jog-Panel**  | Operator / Teach | Manuell fahren, Punkt teachen (existiert bereits) |
| **Backend (ROS 2)** | Logik | YAML lesen, MoveIt aufrufen, State-Übergänge, Cancel, Punkt-Services  |

## Pakete

- **NEU**: `r0192_program_executor` — Backend (Action Server, YAML-I/O, Punktverwaltung)
- **Erweitern**: `r0192_rviz_plugins` — zweites Panel "Program Panel" (Run-Panel, KEIN Editor)
- **Erweitern**: `r0192_interfaces` — neue msgs/srvs/actions
- **NEU** (Config-only): `.vscode/`-Verzeichnis im Repo-Root + JSON Schemas in `doku/schemas/`

## Datenmodell (FINAL — in Phase 0 abgestimmt, 2026-06-11)

> **Update 2026-06-13**: Dieser Abschnitt beschreibt das in Phase 0 abgestimmte **v1-Modell**. Es wurde in den Phasen 5/7/8 **additiv erweitert** (das v1-Modell bleibt unverändert gültig). Die Erweiterungen — KRL-Vokabular `ptp`/`lin`/`circ`, die Goal-Felder `blend`/`dry_run`, der `STATUS_PAUSED`-Feedback-Status und die Pause-/Override-Interfaces — sind unten im Block **„Erweiterungen seit v1"** zusammengefasst. **Source of Truth** für das Endmodell sind die JSON Schemas in `doku/schemas/` und die `.action`/`.srv`-Dateien in `r0192_interfaces`.

### Punktdatei `points.yaml`

```yaml
version: 1
points:
  pick_home:
    type: joint
    joints: [0.0, -0.5, 1.2, 0.0, 1.0, 0.0]   # rad, Reihenfolge joint_1..joint_6
  drop_position:
    type: pose
    frame: base_link                            # v1: nur base_link erlaubt
    position: {x: 0.3, y: 0.2, z: 0.4}          # m
    orientation: {x: 0.0, y: 0.0, z: 0.0, w: 1.0}
```

Festgelegt:
- **Map keyed by name** (kein Array) — Namens-Eindeutigkeit gratis, direkte Referenz, JSON-Schema-Validierung via `patternProperties`. Namensregel `^[A-Za-z_][A-Za-z0-9_]*$`.
- **`joints:`** statt generischem `values:` (expliziter, review-freundlicher). Genau **6 Werte** (Gruppe `r0192_arm`); Greifer ist kein Punkt-Bestandteil.
- `frame`: String mit Default `base_link`; Executor lehnt in v1 andere Frames ab.
- `version: 1` für spätere Migrationen.

### Programmdatei `program_*.yaml`

```yaml
version: 1
name: "Pick and Drop Demo"
description: "Holt Objekt von A und legt es bei B ab"   # optional
defaults:                # optional, gilt für Steps ohne eigene Angabe
  velocity: 0.2
  acceleration: 0.2
steps:
  - type: move_j
    target: pick_home
    velocity: 0.3        # Skalierungsfaktor (0, 1], NICHT rad/s
    acceleration: 0.3
  - type: wait
    duration: 2.0        # Sekunden
  - type: move_l
    target: drop_position
    velocity: 0.1
```

Festgelegt:
- **Step-Typen v1: `move_j`, `move_l`, `wait`** — keine Loops/Conditions.
- **`velocity`/`acceleration` sind einheitenlose Skalierungsfaktoren (0, 1]** (MoveIt `velocity_scaling_factor`); physikalische Einheiten erst mit Pilz (Phase 7). Override-Slider (Phase 5) multipliziert sich drauf.
- **`move_j` akzeptiert joint- und pose-Punkte** (pose → `setPoseTarget`); **`move_l` nur pose-Punkte** (v1).
- Optionales `name:` pro Step für die Anzeige im Run-Panel.

### Storage-Layout (final)

```
<workspace>/programs/          # im Repo (git-diff-bar), Default des Executors
├── points.yaml
└── program_*.yaml
doku/schemas/                  # JSON Schemas (Phase 2) = Source of Truth
```

Im Workspace statt `~/.r0192/`: Programme sind git-versioniert (Prinzip 5), das `.vscode/`-Schema-Mapping greift im geöffneten Workspace, Engineering-Workflow läuft dort. Pfade als ROS-Parameter (`programs_dir`, `points_file`) überschreibbar.

### ROS-Interfaces (final, in `r0192_interfaces`)

- **`action/ExecuteProgram.action`** — Goal: `string program_path` (nur Pfad, kein Inhalt — Datei bleibt Source of Truth, Validierung nur im Backend-Loader). Result: `success`, `message`, `steps_completed`. Feedback: `current_step`, `total_steps`, `step_type`, `step_label`, `status` (`STATUS_LOADING/PLANNING/MOVING/WAITING`).
- **`srv/TeachPoint.srv`** (Phase 4) — `name`, `type` (`TYPE_JOINT`/`TYPE_POSE`), `overwrite` → `success`, `message`.
- **`srv/ListPoints.srv`** (Phase 4) — → `names[]`, `types[]`.
- **`srv/DeletePoint.srv`** (Phase 4) — `name` → `success`, `message`.
- **Kein `SavePoint` in v1** — explizite Werte schreibt man in VS Code direkt in `points.yaml` (Schema-validiert); ein Service wäre ein redundanter zweiter Schreibpfad. Bei Bedarf später additiv.

Die JSON Schemas in `doku/schemas/` (Phase 2) sind die Source of Truth für VS-Code-Autocomplete und Validierung.

### Erweiterungen seit v1 (Phasen 5/7/8 — additiv, v1 bleibt gültig)

**KRL/Pilz-Step-Vokabular (Phase 7)** — koexistiert mit den Legacy-Steps; `move_j`/`move_l` sind als *deprecated, prefer ptp/lin* markiert:

```yaml
steps:
  - type: ptp                # Pilz PTP (Punkt-zu-Punkt), joint- oder pose-Ziel
    target: pick_home
    vel: 0.3                  # Skalierungsfaktor (0,1]  — KRL-Steps nutzen vel/acc (NICHT velocity/acceleration)
    acc: 0.3
  - type: lin                # Pilz LIN (kartesische Linie), nur pose-Ziel
    target: drop_position
    vel: 0.1
    c_dis: 0.02              # optionaler Blend-Radius in m (nur im blend-Modus wirksam)
  - type: circ               # Pilz CIRC (Kreisbogen), nur pose-Ziel
    target: arc_end
    via: arc_mid             # Hilfspunkt (Pose), zwingend; nicht kollinear zu Start/Ziel
    vel: 0.1
```

- **Zwei Run-Modi (Goal-Feld `blend`)**: `false` = „stop at each point" (je Step ein Plan via `MoveGroupInterface`, `c_dis` ignoriert, `circ` abgelehnt); `true` = „blend through" (zusammenhängende Move-Steps als ein `MotionSequenceRequest` an `/sequence_move_group`, `blend_radius=c_dis`, `circ`-`via` als „interim"-Constraint). `wait`-Steps trennen eine Sequenz.
- **Simulationsmodus (Goal-Feld `dry_run`)**: plant das ganze Programm als Pilz-Sequenz mit `plan_only`, animiert es auf `/display_planned_path` (RViz-Geist), bewegt den Arm **nicht** und ändert den Zustand **nicht** (kein MOVEIT); läuft aus jedem Zustand. *(Erfüllt zugleich die in Phase 6 offen gelassene „Trajektorien-Preview".)*
- **Pose-Referenzlink für `lin`/`circ`/`move_l`**: kartesische Steps brauchen ein abgewinkeltes Handgelenk — KDL/Pilz können keine Linie durch die joint_5=0-Singularität.

**ExecuteProgram.action — additive Felder** (Endstand): Goal zusätzlich `bool blend`, `bool dry_run`. Feedback zusätzlich `STATUS_PAUSED=4` (zwischen Steps pausiert; `current_step` = nächster Step). `step_type` deckt nun `move_j`/`move_l`/`wait`/`ptp`/`lin`/`circ` ab.

**Pause & Override (Phase 5) — zusätzliche Interfaces**:
- `srv/SetProgramOverride.srv` → Service `/set_program_override` (klemmt [0.1, 1.0]) + latched Topic `/program_override` (`std_msgs/Float32`, Ist-Wert).
- `/pause_program` + `/resume_program` (`std_srvs/Trigger`) — „Pause after current step", Zustand bleibt `MOVEIT`.

**Punkt-Visualisierung (Phase 6)**: latched `MarkerArray` auf `/program_points_markers` (Kugel + Namens-Label je Punkt).

---

## ToDo

### Phase 0 — Design & Schema festklopfen (kein Code) ✅ (2026-06-11)

- [x] YAML-Schema für Punkte final festlegen (joint vs. pose, Frame-Handling) — siehe „Datenmodell (FINAL)"
- [x] YAML-Schema für Programme final festlegen (Step-Typen, Parameter pro Typ)
- [x] Step-Typen für v1 entschieden: `move_j`, `move_l`, `wait` — keine Loops/Conditions
- [x] `ExecuteProgram.action` festgelegt (Goal: nur Programm-Pfad; Feedback: Step-Index/-Typ/-Label + Status; Result: success/message/steps_completed)
- [x] Service-Interfaces für Punkte festgelegt: `TeachPoint`, `ListPoints`, `DeletePoint` — **kein `SavePoint` in v1** (VS Code editiert `points.yaml` direkt)
- [x] Dateipfade & Storage-Layout festgelegt: `<workspace>/programs/` + `programs/points.yaml` (im Repo, per ROS-Parameter überschreibbar)

### Phase 1 — Backend MVP (`r0192_program_executor`) ✅ (2026-06-11)

- [x] Neues Paket angelegt, in Workspace + Bringup registriert (`real_robot.launch.py`, Node `r0192_program_executor`)
- [x] `ExecuteProgram.action` in `r0192_interfaces` ergänzt (Punkt-Services folgen in Phase 4)
- [x] YAML-Loader mit Schema-Validierung (`program_loader.cpp`: Punkte + Programme, strikte Fehlermeldungen `<file>: <step/point>: <problem>`, unbekannte Keys abgelehnt)
- [x] Action Server `ExecuteProgram` lauffähig (`wait`-Step mit Cancel-responsiven 50-ms-Ticks)
- [x] `move_j` implementiert: Punkt aus DB → `MoveGroupInterface` (lazy erstellt, da move_group später startet) → planen → ausführen; joint- und pose-Ziele
- [x] State-Übergang im Executor: vor Start `HOLD → MOVEIT`, am Ende `MOVEIT → HOLD` — nur wenn der Zustand noch `MOVEIT` ist (nach `/e_stop` wird nichts angefasst)
- [x] Cancel-Verhalten: Action-Cancel ruft `MoveGroupInterface::stop()`, Worker beendet als CANCELED, sauber nach `HOLD` (getestet)
- [x] Feedback publiziert: Step-Index, Label, Gesamt-Steps, Status (LOADING/PLANNING/MOVING/WAITING)
- [x] **Acceptance erfüllt** (virtueller Modus, 2026-06-11): 4-Schritt-Demo (`programs/program_demo.yaml`) läuft via `ros2 action send_goal` durch → SUCCEEDED, Zustand zurück in `HOLD`. Zusätzlich getestet: Cancel mid-program → CANCELED + `HOLD`; Goal aus `DISABLED` → ABORTED mit Manager-Meldung; ungültiger Step-Typ → ABORTED mit präziser Loader-Meldung. **Hardware-Test an Achse 1/4 steht aus.**

### Phase 2 — VS-Code-Integration (Engineering) ✅ implementiert (2026-06-11, Acceptance manuell offen)

> Klein, aber sehr früh wertvoll: macht das Schreiben/Bearbeiten von Programm- und Punktdateien angenehm und sicher. Damit kannst du im weiteren Verlauf Programme zum Testen schnell und ohne Tippfehler schreiben.

- [x] JSON Schema für `program.yaml` geschrieben (`doku/schemas/program.schema.json`)
- [x] JSON Schema für `points.yaml` geschrieben (`doku/schemas/points.schema.json`)
- [x] `.vscode/extensions.json` mit Empfehlung für `redhat.vscode-yaml` angelegt
- [x] `.vscode/settings.json` mit Schema-Mapping ergänzt (bestehende Settings beibehalten); `.gitignore` von `\.vscode/` auf selektives Whitelisting umgestellt (settings/extensions/snippets committet, Rest ignoriert)
- [x] `.vscode/r0192.code-snippets`: `r0192-program`, `move_j`, `move_l`, `wait`, `point-joint`, `point-pose`
- [x] Im Haupt-README dokumentiert (Abschnitt „Roboterprogramme")
- [ ] **Acceptance** (manuell in VS Code zu verifizieren): Neue `program_*.yaml` aus Snippet erzeugen, ungültiger Step-Typ wird live markiert, Autocomplete + Hover funktionieren. (Schemas wurden bereits maschinell gegen die Beispieldateien validiert, inkl. Negativtest.)

### Phase 3 — RViz Run-Panel MVP (`r0192_rviz_plugins`) ✅ (2026-06-12, Acceptance erfüllt)

> Bewusst minimaler Scope: nur Runtime, kein Editor. Editiert wird in VS Code.

- [x] Panel-Klasse `ProgramPanel` (Subklasse von `rviz_common::Panel`) angelegt
- [x] In `plugin_description.xml` registriert, CMakeLists/package.xml erweitert (`rclcpp_action`); zusätzlich im Default-Layout `moveit.rviz` als „R0192 Program" — erscheint beim Start automatisch
- [x] UI-Layout: Datei-Combo über `programs/` (+ Refresh + Browse, Verzeichnis wird in der RViz-Config persistiert), Programm-Anzeige read-only mit YAML-`QSyntaxHighlighter`, Buttons Run/Stop
- [x] Action-Client für `ExecuteProgram`; Goal mit absolutem Pfad, Datei wird vor Run frisch von Platte gelesen (View = was der Executor lädt)
- [x] Live-Highlighting des aktuell ausgeführten Steps (Step-Index → `- `-Items nach `steps:` im Dokument, Amber-Block + Auto-Scroll)
- [x] Stop-Button → Action-Cancel → Executor stoppt Bewegung (`stop()`) und kehrt sauber nach `HOLD` zurück
- [x] Status-Display: „Step X / Y — label [status]", Robot-State-Label, Statuszeile; state-getriebene UI (Run nur in `HOLD`/`MOVEIT`, Dateiauswahl während Run gesperrt)
- [x] **Acceptance erfüllt** (manuell in RViz, 2026-06-12): Programm über UI geladen, ausgeführt und gestoppt; Step-Highlight sichtbar; State-Übergänge MOVEIT→HOLD im Log bestätigt.

### Phase 4 — Punktverwaltung & Teach ✅ implementiert (2026-06-12, Acceptance manuell offen)

- [x] Services `/teach_point`, `/list_points`, `/delete_point` im Backend implementiert (kein `SavePoint` — Phase-0-Entscheidung: explizite Werte schreibt VS Code direkt). YAML-Writer schreibt atomar (tmp+rename), schema-valide; **Achtung: Hand-Kommentare in `points.yaml` überleben einen Teach/Delete-Rewrite nicht** (Header-Kommentar in der Datei weist darauf hin)
- [x] `TeachPoint`: Joint-Typ aus `/joint_states` (joint_1..6), Pose-Typ via TF `base_link` → `pose_reference_link` (Param, Default `gripper_base` = EE-Link der Planning Group, damit die Pose beim Abspielen exakt reproduziert wird). Nur in `HOLD`/`JOG` erlaubt
- [x] Punktdatei live nachladen: service-getriggert — jede List/Teach/Delete-Anfrage und jedes Programm-Goal liest die Datei frisch (kein File-Watcher nötig)
- [x] UI-Erweiterung im Run-Panel (`ProgramPanel`, Gruppe „Points"): Punktliste (Name + Typ), Refresh, Teach (Name + joint/pose, nur in `HOLD`/**`JOG`** aktiv, Overwrite-Rückfrage), Delete mit Bestätigungsdialog. **Rename bewusst weggelassen** — Umbenennen ist eine Engineering-Aktion (VS Code, mit Suchen/Ersetzen der Referenzen)
- [x] Services per CLI getestet (2026-06-12, virtuell): List/Teach joint/Teach pose/Overwrite-Ablehnung/Delete/Unknown-Delete/State-Gating alle OK; regenerierte `points.yaml` schema-valide; Demo-Programm läuft aus der regenerierten Datei
- [x] **Acceptance erfüllt** (real, 2026-06-12): Teach joint+pose über das Panel bestätigt (inkl. Pose-Teach auf Achse 4); TF-Listener-Bug gefixt (eigener Spin-Thread). *Hinweis: Namens-Autocomplete über Dateigrenzen kann ein statisches JSON Schema nicht leisten — das kommt erst mit der VS-Code-Extension (Phase 9); das Schema validiert das Namensmuster.*

### Phase 5 — Pause & Override ✅ (2026-06-12, Acceptance erfüllt)

> Hier zwei Features mit ehrlichen technischen Caveats — bitte im Backend sauber implementieren, nicht "irgendwie reinhacken".

- [x] **Pause-Implementierung**: „Pause after current step" — `/pause_program` + `/resume_program` (`std_srvs/Trigger`, Executor). Laufender Step wird beendet, dann hält der Worker vor dem nächsten Step; **Zustand bleibt `MOVEIT`** (Goal besitzt die Zustandsmaschine weiter — kein HOLD-Ping-Pong, kein JOG-Konfliktfenster), JTC hält die Position. Feedback-Status `STATUS_PAUSED=4` (additiv in `ExecuteProgram.action`); Cancel aus der Pause heraus funktioniert. UI-Button „Pause (after step)"/„Resume", paused-Flag folgt dem Action-Feedback
- [x] **Speed-Override-Slider** im UI (10–100 %), folgt dem autoritativen latched Topic statt optimistisch zu schalten
- [x] Override wirkt auf den **nächsten** Step (Multiplikation der `velocity`/`acceleration`-Skalierung beim Planen; (0,1]×[0.1,1] bleibt in (0,1]). Live-Override auf laufender Trajektorie kommt mit Pilz (Phase 7)
- [x] Backend: **Service `/set_program_override`** (`SetProgramOverride.srv`, klemmt auf [0.1, 1.0]) + **latched Topic `/program_override`** (`std_msgs/Float32`, Ist-Wert) — Haus-Muster wie `/set_robot_state` + `/robot_state`; Executor liest den Wert vor jedem Plan-Aufruf; Reset auf 1.0 bei Neustart
- [x] Headless getestet (2026-06-12, virtuell): Override 0.3 angewendet / 0.05→0.1 geklemmt / latched Topic korrekt; Pause ohne Programm abgelehnt; Pause mid-run → hält nach aktuellem Step (PAUSED vor Step 2), bleibt stabil, Resume → SUCCEEDED (4 Steps); Cancel während Pause → CANCELED
- [x] **Acceptance erfüllt** (manuell, 2026-06-12): Override 0.21 → nächster `move_j` ~4× langsamer (Log); Pause vor Step 3 → Resume setzt fort, Programm SUCCEEDED.

### Phase 6 — MoveL (Kartesisch) & Visualisierung ✅ implementiert (2026-06-12, Acceptance manuell offen)

- [x] `move_l` im Executor: `computeCartesianPath()` (eef_step via Param `cartesian_eef_step`, Default 5 mm). **Retiming serverseitig**: die Skalierungsfaktoren (`velocity`/`acceleration` × Override) gehen im Service-Request mit; move_group wendet TOTG mit den `joint_limits.yaml`-Limits an (das Client-Robotermodell hat keine Beschleunigungslimits — clientseitiges TOTG schlug deshalb fehl). `fraction < 99.9 %` → sauberer Abbruch mit Prozentangabe; Null-Distanz (< 2 Trajektorienpunkte) = No-op-Erfolg
- [x] **Wichtige Erkenntnis (getestet)**: KDL kann **keine Linie durch die Handgelenk-Singularität joint_5 = 0** verfolgen (alle bisherigen Demo-Punkte lagen dort → 0 % feasible). `move_l`-Punkte brauchen ein abgewinkeltes Handgelenk; Fehlermeldung weist darauf hin. Langfristige Alternative: TRAC-IK (siehe Known Issues)
- [x] Punkt-Visualisierung im RViz 3D-View: `MarkerArray` auf **`/program_points_markers`** (latched) — Kugel + Namens-Label je Punkt aus `points.yaml` (pose = orange, joint = blau via FK, sobald das Robotermodell verfügbar ist); Republish bei Teach/Delete/List; Display „ProgramPoints" in `moveit.rviz`. *Bewusst keine interaktiven Marker* — ohne Edit-Funktion (Editieren = VS Code) wäre Interaktivität nur Schein
- [x] Optional: Trajektorien-Preview vor Ausführung — **nachträglich durch den Dry-Run-Modus (Phase 8) erfüllt** (`dry_run`-Goal plant + animiert das Programm als RViz-Geist, ohne den Arm zu bewegen)
- [x] Headless getestet (2026-06-12, virtuell): gemischtes `move_j`/`move_l`-Programm (`programs/program_linear_demo.yaml`, Punkte `bent_a`/`bent_b`/`lin_bent`) SUCCEEDED; Wiederholung mit Null-Distanz-`move_l` SUCCEEDED; Marker-Topic liefert Kugel+Label für alle Punkte; Singularitäts-Fall bricht sauber mit klarer Meldung ab
- [ ] **Acceptance** (manuell in RViz): `program_linear_demo.yaml` läuft sichtbar (PTP, PTP, Linearbewegung), Punkte im 3D-View sichtbar und benannt.

### Phase 7 — Pilz Industrial Motion Planner + KRL-Vokabular ✅ funktional abgeschlossen (2026-06-13)

> **Status**: Vokabular, sequenzielles Pilz-Routing und der Blend-/Sequence-Modus (inkl. `circ`) sind implementiert und real bestätigt. **Einzige bewusste Limitation**: echtes Live-Override auf einer laufenden Trajektorie (braucht Stop+Replan) — als Folgearbeit eingeordnet, siehe `[~]`-Punkt unten.

> Ab hier macht es Sinn, sich beim Befehlsvokabular an etablierten Industrie-Sprachen zu orientieren statt es selbst zu erfinden. **KUKA KRL** (Robot Language der klassischen KR-Industrieserie) ist die natürliche Wahl, weil ihre Kernbefehle (`PTP`, `LIN`, `CIRC`) **exakt das sind, was Pilz erwartet** — die Step-Typen mappen sich quasi von selbst. KRL ist in Schulungsmaterial und Lehrbüchern frei dokumentiert, IP-rechtlich unproblematisch. (Hinweis: KUKA Sunrise / iiwa Java-API NICHT als Referenz nehmen — proprietär, nur mit Lizenz zugänglich.)

- [x] Pilz im MoveIt-Setup als Planning Pipeline aktiviert (`moveit.launch.py`: `planning_pipelines(pipelines=["ompl", "pilz_industrial_motion_planner"])`, `pilz_cartesian_limits.yaml` vorhanden)
- [x] Neue Step-Typen mit KRL-Vokabular eingeführt: `ptp`, `lin`, `circ` mit `vel`, `acc`, `c_dis` (Blend-Radius in m); `circ` zusätzlich mit `via` (Hilfspunkt). Loader (`program_loader.cpp`) + `crossValidate` erweitert (lin/circ brauchen Pose-Ziele, circ-`via` muss Pose sein)
- [x] **Backward Compatibility** — bewusst **konservativer** als der ursprüngliche Plan: statt `move_j`/`move_l` intern auf `ptp`/`lin` umzubenennen, **koexistieren** beide Vokabulare. `move_j`/`move_l`/`wait` behalten ihre **validierten** Phase-1/6-Pfade (OMPL bzw. KDL `computeCartesianPath`) **unverändert** (Null-Regressionsrisiko); `ptp`/`lin`/`circ` sind die neuen Pilz-Pfade. Alte Programme laufen ohne Migration weiter; Schema + Snippets markieren `move_j`/`move_l` als *deprecated, prefer ptp/lin*
- [x] JSON Schema erweitert (`program.schema.json`): `ptp`/`lin`/`circ` + `blendRadius`-Definition parallel zu `move_j`/`move_l`; headless gegen alle Beispielprogramme + Negativtests validiert (jsonschema)
- [x] Snippets aktualisiert (`r0192.code-snippets`): `ptp`/`lin`/`circ` als Default-Snippets, Programm-Skelett nutzt `ptp`; `move_j`/`move_l` als „(deprecated)" behalten
- [x] Executor-Routing (sequenziell): `ptp` → Pilz `PTP`, `lin` → Pilz `LIN` (`setPlanningPipelineId("pilz_industrial_motion_planner")` + `setPlannerId`, danach Reset auf `ompl`); `c_dis > 0` wird geloggt + ignoriert (Blending fehlt noch); `circ` zur Laufzeit sauber abgelehnt (Datenmodell steht, kommt mit dem Sequence-Modus — gleiches Muster wie `move_l` vor Phase 6)
- [x] Executor-Modus „Pilz Sequence" (`runBlendedRun`): bei `blend == true` (neues additives Goal-Feld in `ExecuteProgram.action`) werden zusammenhängende Move-Steps als **ein** `MotionSequenceRequest` an die **`/sequence_move_group`**-Action geschickt (Planner je Step, `blend_radius = c_dis`, letztes Item zwingend 0; `circ`-`via` als „interim"-Path-Constraint; Start-State leer → Pilz verkettet). Wait-Steps trennen eine Sequenz. Cancel bricht das Sequence-Goal ab. Capability `pilz_industrial_motion_planner/MoveGroupSequenceAction` in `moveit.launch.py` ergänzt. Damit ist auch die **`circ`-Laufzeit** frei (im Stop-at-each-point-Modus weiterhin sauber abgelehnt: „circ requires blend mode")
- [x] UI-Toggle „Blend through (Pilz)" im ProgramPanel (`QCheckBox`, setzt `goal.blend`; während Run gesperrt)
- [x] Polish (2026-06-13): erstes Sequence-Item bekommt den Live-Robot-State als Start-State → beseitigt das kosmetische `Found empty JointState message`-Log-Rauschen (move_group fährt ohnehin vom Ist-Zustand); CIRC-Fehlermeldung um den Kollinear-/Ebenen-Hinweis erweitert
- [~] **Echtes Live-Override** auf laufender Trajektorie: **als Limitation eingeordnet, nicht umgesetzt** — MoveIt/Pilz kann eine bereits gesendete Trajektorie nicht ohne Stop+Replan umskalieren. Override wirkt daher (wie dokumentiert) ab dem nächsten Step/der nächsten Sequenz. Echtes Mid-Trajektorien-Override bräuchte einen Stop-und-Replan-Mechanismus (eigener Folge-Task, kein reiner Phase-7-Scope)
- [x] Demos: `programs/program_blend_demo.yaml` (ptp+ptp mit `c_dis`+lin), `programs/program_circ_demo.yaml` (CIRC-Template); beide schema-valide
- [x] **Acceptance Blend bestätigt** (manuell gegen move_group, 2026-06-13): `program_blend_demo.yaml` mit `blend: true` → „MoveGroupSequenceAction" + „trajectory_blender_transition_window" + Intersection-Points → **eine** geblendete Trajektorie, SUCCEEDED. circ-Pfad bestätigt erreichbar (Pilz „Generating CIRC trajectory"); das Template scheitert erwartungsgemäß an kollinearen Platzhalter-Punkten → braucht reichbare, nicht-kollineare Bogen-Punkte
- [x] Headless getestet (2026-06-13, virtuell): Schema-Validierung (alle Programme + 3 Negativtests OK); C++-Loader akzeptiert `program_krl_demo.yaml` (`ptp`/`lin`), lehnt `circ`-ohne-`via`, joint-`via`, joint-Ziel bei `lin` und Fremd-Key `velocity` bei `ptp` mit präzisen Meldungen ab; Build sauber. Demo `programs/program_krl_demo.yaml` (`ptp`+`lin`)
- [x] **Pilz-Laufzeit bestätigt** (manuell gegen laufende move_group, 2026-06-13): `program_krl_demo.yaml` lief sichtbar über den Pilz-Pfad durch — „Generating PTP trajectory" (ptp) + „Generating LIN trajectory" (lin), beide Ausführungen SUCCEEDED, Programm beendet → State HOLD. (Segfault beim Ctrl-C-Teardown = bekannter Upstream-Bug, harmlos.) **Offen: circ/Blending** (Sequence-Modus)

### Phase 8 — Robustheit & Polish 🚧 in Arbeit (2026-06-13)

- [x] **Unit-Tests für den YAML-Parser** (`test/test_program_loader.cpp`, `ament_add_gtest`): 25 Tests, alle grün — Punkte (joint/pose, Quaternion-Norm, Frame, Keys, Namen, Version), beide Step-Vokabulare (`ptp`/`lin`/`circ`/`move_j`/`move_l`/`wait`, vel/acc/c_dis/via, Defaults), Reject-Pfade (circ-ohne-via, negatives c_dis, Skalierung außer Bereich, Fremd-Keys, leere Steps, …), `crossValidate`, `savePoints`-Round-Trip, `isValidPointName`, `Step::label`. Loader-Quelle wird in den Test einkompiliert (kein Link gegen den Node)
- [x] README-Eintrag im Hauptrepo aktualisiert: Step-Vokabular-Tabelle (KRL + Legacy), beide Run-Modi (`blend`), `circ`-Nicht-Kollinearität, Blend-CLI-Beispiel
- [x] Roadmap im Haupt-README angepasst: Programm-System als erledigt eingetragen (ersetzt für die Programmierung das geplante Web-Interface)
- [x] Fehlerbehandlung Executor — Notaus während Ausführung: bereits robust (der Worker spiegelt `/robot_state`; nach `/e_stop` → DISABLED gibt der Sequence-/Move-Action-Result `!=SUCCEEDED` zurück, der Executor bricht sauber ab und fasst den Zustand **nicht** an). Planungs-/Ausführungsfehler liefern präzise Meldungen (inkl. CIRC-Kollinear-Hinweis)
- [x] **Dry-Run / Simulationsmodus** (2026-06-13): additives Goal-Feld `dry_run`. `true` = ganzes Programm wird als Pilz-Sequenz **nur geplant** (`planning_options.plan_only`), die geplanten Trajektorien werden auf `/display_planned_path` publiziert und als RViz-Geist animiert (Dauer-getaktet, cancel-responsiv) — **der echte Arm bewegt sich nicht**, **kein** State-Wechsel (kein MOVEIT, Motoren bleiben wie sie sind), Waits werden übersprungen, läuft aus **jedem** Zustand. `circ`/Blending werden mitsimuliert (Sequence-Pfad). UI: Toggle „Simulate (dry run)" im ProgramPanel; Run ist im Dry-Run aus jedem Zustand freigegeben. Löst zugleich die „Vorschau zu schnell/überlappt"-Frage: Simulation = Geist allein, echter Lauf = man schaut auf den echten Arm
- [ ] Integrationstest für Executor (mit Sim oder ros2_control Mock) — offen (braucht laufende move_group/Controller; v1 über die manuellen Hardware-Läufe abgedeckt)

### Phase 9 (optional) — Eigene VS-Code-Extension

> Nur bei echtem Bedarf. Bis dahin reicht JSON Schema + `.vscode/`-Config.

- [ ] Validierung von Punktnamen gegen Live-Punktdatenbank (per ROS-Bridge oder File-Read)
- [ ] "Send to robot"-Button direkt aus VS Code
- [ ] "Go to point definition" (Cmd-Click auf Punktnamen springt zu `points.yaml`)
- [ ] Inline-Diagnostics für nicht-existierende Punkte

---

## Kickoff-Prompt für AI Coding Agent

> Diesen Prompt kannst du Claude Code oder einem anderen Coding-Assistenten geben, um eine Phase zu starten. Setze `[PHASE]` und die Tasks/Acceptance der jeweiligen Phase aus dem ToDo oben ein.

```text
Du arbeitest am ROS 2 Jazzy Projekt R0192-Roboticarm
(Repo: fHund3D/R0192-Roboticarm). Lies zuerst CLAUDE.md und README.md
im Repo-Root für den Projektkontext und die bestehende Paketstruktur.

# Ziel
Wir erweitern das Projekt um eine industriell-typische Trennung
zwischen Engineering und Operations:
- VS Code als Engineering-Tool (Programme schreiben, YAML + JSON Schema)
- RViz-Panel als Operator-/Runtime-Interface (Laden, Run, Pause, Stop,
  Override, aktuelle Programmzeile)
- Backend in ROS 2 (Action Server, YAML-Loader, Punktverwaltung)

# Architektur-Prinzipien (NICHT VERHANDELBAR)
1. Strikte Trennung Backend/UI/Editor: Backend ist die einzige Stelle
   mit Geschäftslogik. RViz-Panel = Runtime-Client. VS Code = Editor.
   Kommunikation nur über ROS 2 Actions/Services und Dateien (YAML).
2. State-Management ausschließlich über /set_robot_state (siehe
   robot_state_manager). Niemals direkt /robot_enable, /homing,
   pause_servo oder Controller-Switch aufrufen. Programmausführung
   läuft im MOVEIT-State, am Ende immer zurück nach HOLD.
3. MoveIt sequenziell für v1: MoveGroupInterface step-by-step.
   Pilz Industrial Motion Planner ist eine spätere Phase, jetzt nicht.
4. Punkte vs. Programme getrennt: Programme referenzieren Punkte per
   Name. Keine inline-Posen in Programmschritten.
5. Programme sind YAML, kein Custom-DSL. Die Schemas in doku/schemas/
   sind die Source of Truth.

# Neue/erweiterte Pakete
- NEU: r0192_program_executor (Backend)
- Erweitern: r0192_rviz_plugins (Run-Panel, KEIN Editor)
- Erweitern: r0192_interfaces (neue msgs/srvs/actions)
- NEU (Config-only): .vscode/ + doku/schemas/

# Aktuelle Phase
[PHASE-NAME, z.B. "Phase 1 — Backend MVP"]

# Tasks dieser Phase
[Hier die Checkbox-Tasks der Phase aus dem ToDo einfügen]

# Acceptance Criteria
[Hier den Acceptance-Punkt der Phase einfügen]

# Vorgehen
1. Erst die Schema-/Interface-Entscheidungen der Phase mit mir abstimmen,
   BEVOR du Code schreibst. Zeige mir geplante msg/srv/action-Definitionen
   und YAML-/JSON-Schemas, warte auf mein OK.
2. Danach inkrementell implementieren: kleine, testbare Commits.
3. Nach jedem Sub-Task: kurze Zusammenfassung der Änderung + wie ich es
   testen kann (Befehle, erwartetes Verhalten).
4. Bei Unsicherheit über Repo-Konventionen: im bestehenden Code nachsehen
   (z.B. wie r0192_rviz_plugins/JogPanel aufgebaut ist) und konsistent bleiben.

# Was du NICHT tun sollst
- KEINEN Programm-Editor ins RViz-Panel einbauen. Editieren ist VS-Code-Sache.
  RViz-Panel ist Runtime-only (Laden, Run/Pause/Stop, Override, Status).
- Keine UI-Logik ins Backend, keine Backend-Logik ins UI.
- Keine direkten Aufrufe von Low-Level-Services unter Umgehung des
  robot_state_manager.
- Keine Web-/HTTP-/REST-Schnittstellen. Nur native ROS 2 Pub/Sub/Service/Action.
- Keine echte VS-Code-Extension in dieser Phase (außer du arbeitest explizit
  an Phase 9). Bis dahin reicht JSON Schema + .vscode/-Config.
- Keine Annahmen über bestehende APIs ohne sie im Repo verifiziert zu haben.
- Keine eigenständigen Refactorings am bestehenden Code ohne Rücksprache.
```

---

## Nutzung dieses Dokuments

Dieses File z.B. als `doku/PROGRAM_IDE_PLAN.md` ins Repo committen. Phasen sequenziell abarbeiten — jeweils Tasks und Acceptance der Phase in den Kickoff-Prompt einsetzen, dem Coding-Agent geben, nach Abschluss Checkboxen abhaken und Acceptance manuell verifizieren. README-Roadmap im Hauptrepo erst am Ende der relevanten Phasen anpassen.

---

## Anhang: Vokabular-Referenzen für spätere Erweiterungen

Wenn ab Phase 7 das Step-Vokabular über die Move-Befehle hinaus erweitert wird (z.B. IO-Operationen, Wartebedingungen, Greifer-Befehle, Frame-/Tool-Konzepte), sind diese öffentlich dokumentierten Industrie-Sprachen als Inspiration sinnvoll:

- **KUKA KRL** — Move-Befehle (`PTP`, `LIN`, `CIRC`), `WAIT FOR`, `OUT`, Frame-Konzepte (`$BASE`, `$TOOL`). Sehr gut dokumentiert in Schulungsmaterial und Lehrbüchern. **Direkter Nutzen für Pilz**, daher Hauptreferenz ab Phase 7.
- **URScript** (Universal Robots) — Manual frei online verfügbar, breites Befehlsspektrum (Force-Modi, IO, Conditional Waits), pythonische Lesbarkeit. Gute Referenz wenn das Vokabular über reine Bewegungen hinaus wachsen soll.
- **ABB RAPID** — Sehr ausgereift, breit dokumentiert; gute Referenz für fortgeschrittene Konzepte wie Speed-Data, Zone-Data, Tool-Data, falls das System mal ein "professionelles" Datentyp-Modell bekommen soll.

**Nicht als Referenz nehmen**: KUKA Sunrise / LBR iiwa Java-API (RoboticsAPI). Proprietär, nur mit Sunrise.Workbench-Lizenz zugänglich. Der Java-Stack würde außerdem nicht in eine ROS-2-Architektur passen.

**Rechtliche Grenze**: Befehlsnamen, Parameter-Konventionen und Konzepte zu übernehmen ist üblich und legitim — APIs sind in dieser Form nicht durch Copyright geschützt. Direkte Implementierungen, Originaldokumentation oder Code-Snippets aus proprietären Quellen NICHT 1:1 übernehmen.

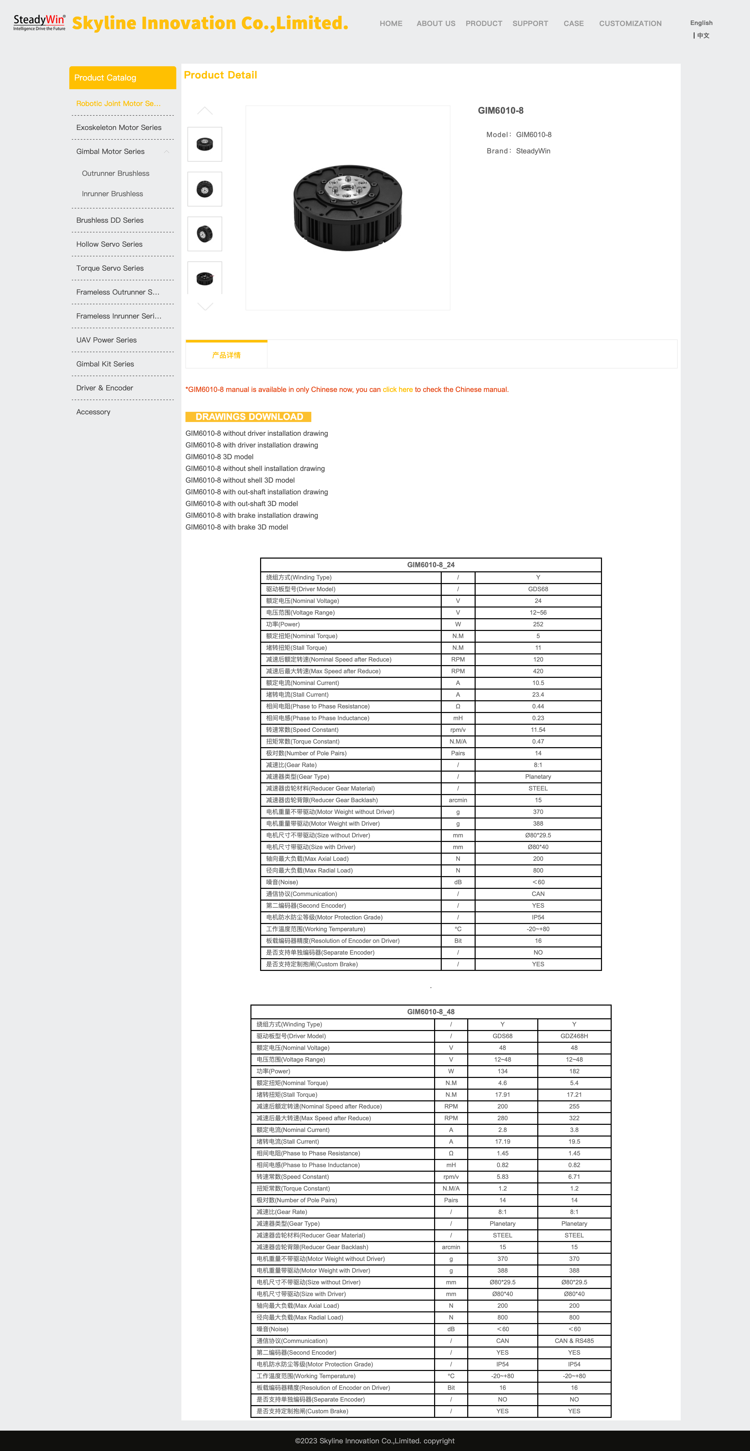
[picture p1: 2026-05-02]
doku/Actuatoren/SteadyWin Actuator/GIM6010-8.png

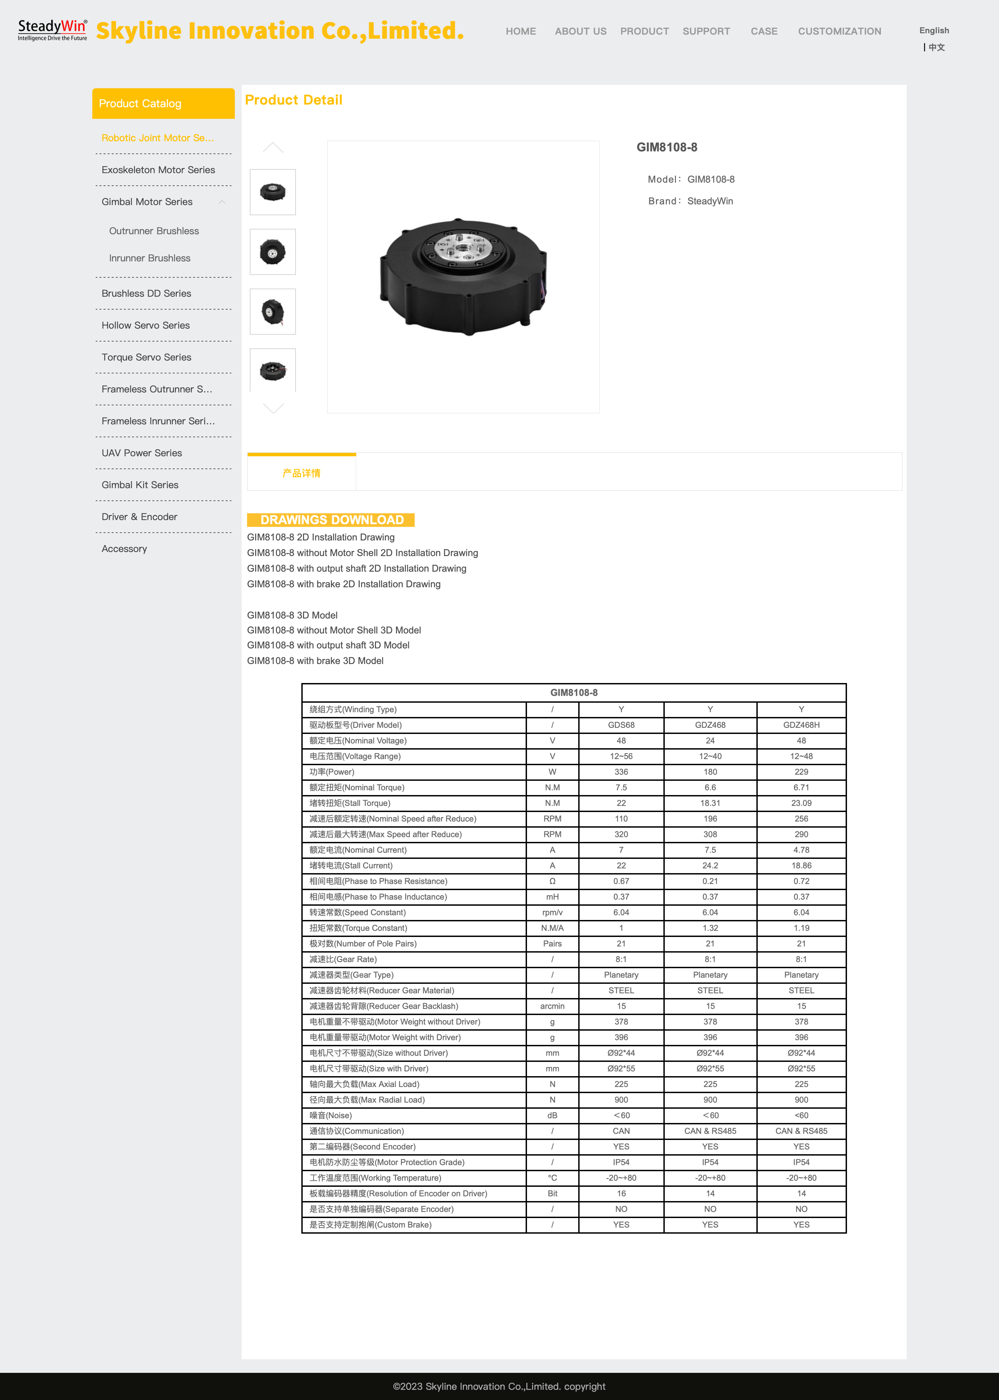
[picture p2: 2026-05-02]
doku/Actuatoren/SteadyWin Actuator/GIM8108-8.png

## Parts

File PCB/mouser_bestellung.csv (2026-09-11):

Hersteller | Herst.-Nr. | Menge | Designator | Beschreibung | Hinweis
Littelfuse | 60R050XU | 10 | F1 | PPTC 60 V, 0,5 A hold / 1 A trip, radial RM 5,1 | ERSETZT MF-RHT050-2 (nur 30 V)
Phoenix Contact | 1770966 | 15 | J1, J2 | PTSM 0,5/3-2,5-V THR R44, 3-polig | ERSETZT 1770953 (2-polig)
Diotec | US1D | 10 | D1 | Ultrafast 200 V / 1 A, SMA (DO-214AC) | ERSETZT US2D (SMB, passt nicht auf D_SMA)
Yageo | CC0603KRX7R9BB104 | 35 | C1, C7, C9, C11, C12 | 100 nF 50 V X7R 0603
Yageo | CC0805KRX7R0BB104 | 10 | C4 | 100 nF 100 V X7R 0805 | 100 V (48-V-Schiene)
Samsung | CL10A105KA8NNNC | 10 | C5 | 1 uF 25 V X5R 0603
Samsung | CL10A225KO8NNNC | 10 | C6 | 2,2 uF 16 V X5R 0603
Samsung | CL21A106KAYNNNE | 10 | C8 | 10 uF 25 V X5R 0805
Murata | GRM1885C1H102JA01D | 10 | C10 | 1 nF 50 V C0G 0603
Murata | GRM1885C1H472JA01D | 10 | C13 | 4,7 nF 50 V C0G 0603 | C0G fuer Split-Termination
Nichicon | UVR2A101MPD | 12 | C2, C3 | 100 uF 100 V Elko, D10 x 20 mm, RM 5 | Bauhoehe 20 mm pruefen
Yageo | RC0603FR-074K7L | 10 | R1 | 4,7 k 1 % 0603
Yageo | RC0603FR-0722RL | 10 | R2 | 22 R 1 % 0603
Yageo | RC0603FR-0710KL | 15 | R3, R4 | 10 k 1 % 0603
Yageo | RC0603FR-071ML | 10 | R6 | 1 M 1 % 0603
Yageo | RC0603FR-07150KL | 10 | R7 | 150 k 1 % 0603 | NICHT 100 k (Sense-Teiler)
Yageo | RC0603FR-076K8L | 15 | R8, R9 | 6,8 k 1 % 0603
Yageo | RC0603JR-070RL | 10 | R10 | 0 R 0603 | nur auf EINEM Board bestuecken
Yageo | RC0603FR-07470RL | 10 | R11 | 470 R 1 % 0603
Yageo | RC0603FR-0760R4L | 15 | R12, R13 | 60,4 R 1 % 0603 | E96, 1 %
Littelfuse | SMAJ5.0CA | 10 | D3 | TVS 5 V bidirektional, SMA
Lite-On | LTST-C191KRKT | 10 | D4 | LED rot 0603
CTS | 219-2LPSTJ | 10 | SW1 | DIP-Schalter 2-pol., Low Profile, J-Bend, 2,54 mm | Split-Termination, passt auf aktuellen Footprint
C&K | PCM12SMTR | 10 | SW3 | Schiebeschalter SPDT, 300 mA @ 6 VDC, SMD, seitlich betaetigt | ERSETZT CHS-01TA1 (100 mA); Footprint -> Button_Switch_SMD:SW_SPDT_PCM12, Symbol SW_SPDT
Wurth Elektronik | 61300411121 | 10 | J6 | Stiftleiste 1x4, RM 2,54, THT vertikal | UART-Debug
JST | PHR-3 | 15 | J3, J5 (Gegenstecker) | PH-Gehaeuse 3-polig
JST | SPH-002T-P0.5S | 100 | J3, J5 (Kontakte) | PH-Crimpkontakt AWG 30-24

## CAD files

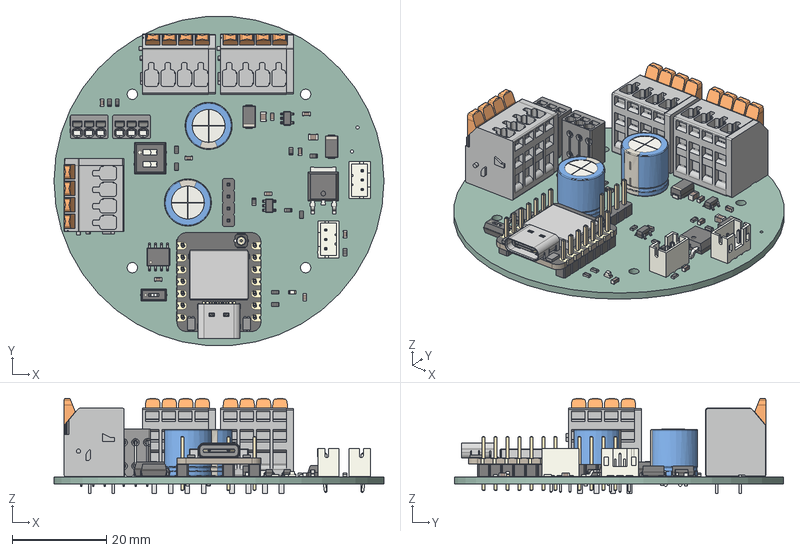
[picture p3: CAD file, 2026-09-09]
PCB/KiCad/.step
70.0 x 69.8 x 20.2 mm
R_0603_1608Metric x 12
D_SMA x 2
CP_Radial_D100mm_P500mm x 2
C_0603_1608Metric x 9
SOT-23-5 x 2
SW_DIP_SPSTx01_Slide_Copal_CHS_01A_W508mm_P127mm_JPin
C_0805_2012Metric x 2
SW_DIP_SPSTx02_Slide_67x664mm_W673mm_P254mm_LowProfile_JPin
LED_0603_1608Metric
JST_B3B_PH_K x 2
932d09b3-9c39-11ed-93f0-dde97e994e83_part
932d09b4-9c39-11ed-93f0-dde97e994e83_part
932d09b5-9c39-11ed-93f0-dde97e994e83_part
SOIC-8_3.9x4.9mm_P1.27mm
PinHeader_1x04_P254mm_Vertical
BOSS-EXTRUDE14_8_
BOSS-EXTRUDE7_4_
BOSS-EXTRUDE7_3_
BOSS-EXTRUDE14_4_
BOSS-EXTRUDE14_2_
BOSS-EXTRUDE14_11_
BOSS-EXTRUDE7_7_
BOSS-EXTRUDE14_9_
BOSS-EXTRUDE14_3_
BOSS-EXTRUDE14_7_
MIRROR2
BOSS-EXTRUDE14_5_
BOSS-EXTRUDE14_12_
BOSS-EXTRUDE7_8_
BOSS-EXTRUDE7_1_
BOSS-EXTRUDE14_10_
BOSS-EXTRUDE7_9_
BOSS-EXTRUDE14_6_
BOSS-EXTRUDE14_1_
BOSS-EXTRUDE7_6_
BOSS-EXTRUDE7_2_
CUT-EXTRUDE5
BOSS-EXTRUDE7_5_
Shield
Pins x 2
U.FL-R-SMT-1_10_ v1
PinHeader_1x07_P254mm_Vertical x 2
DriverDasyChain_PCB

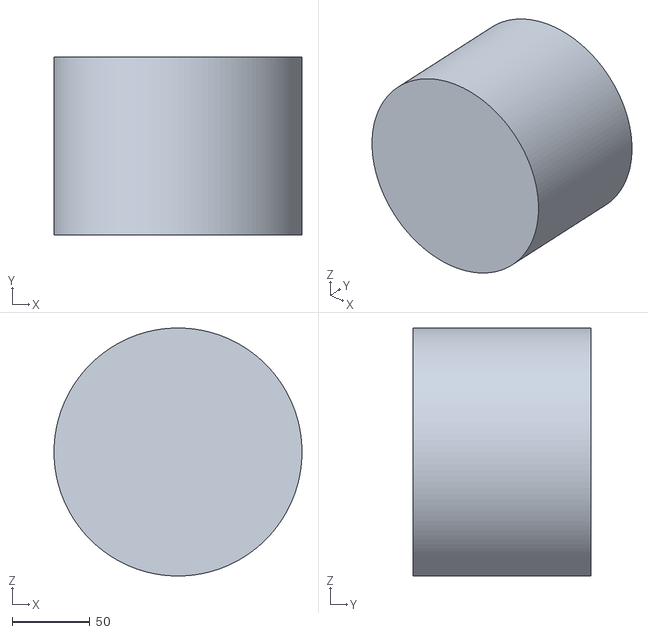
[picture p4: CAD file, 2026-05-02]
src/r0192_description/meshes/collision/axis_1_collision.stl
160.0 x 115.0 x 160.0

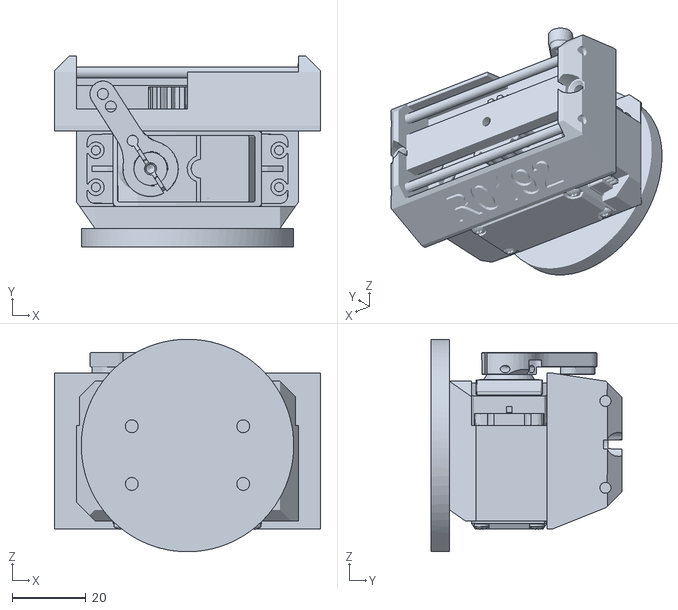
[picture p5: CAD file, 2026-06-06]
src/r0192_description/meshes/gripper/gripper_base.stl
72.0 x 51.8 x 57.5

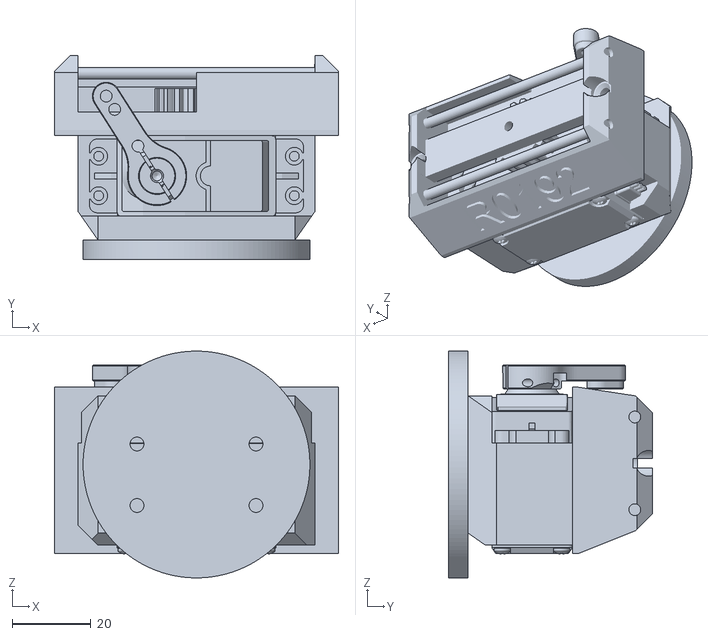
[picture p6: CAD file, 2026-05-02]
src/r0192_description/meshes/gripper/original/gripper_base.stl
72.0 x 51.7 x 57.5

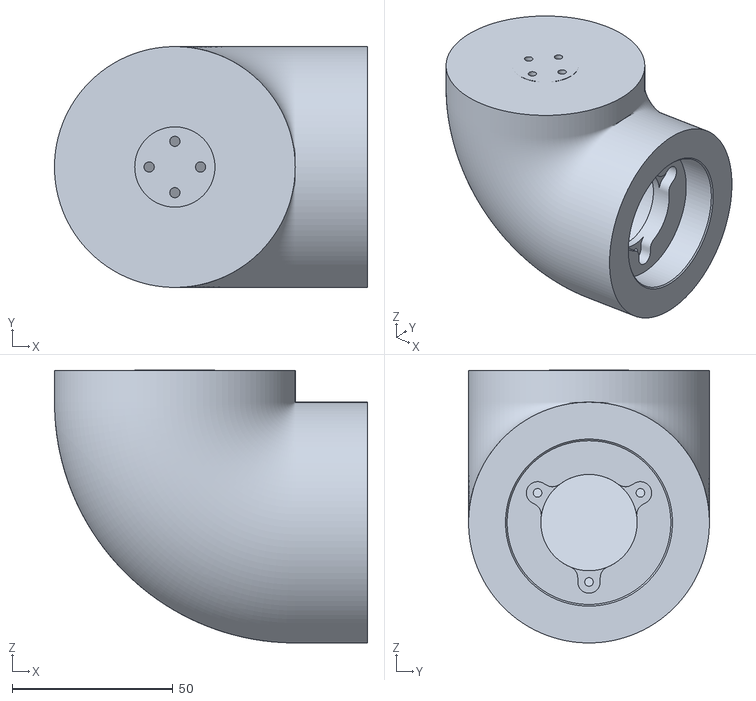
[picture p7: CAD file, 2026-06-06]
src/r0192_description/meshes/visual/axis_6.stl
97.5 x 75.0 x 85.0

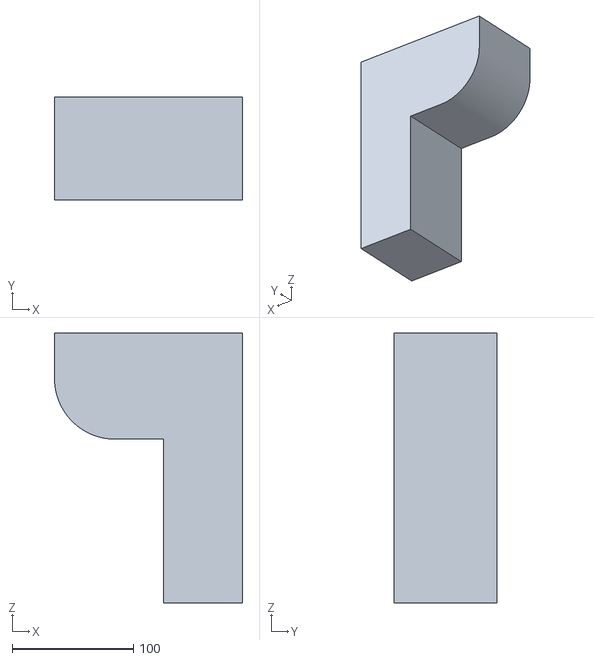
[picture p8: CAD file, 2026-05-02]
src/r0192_description/meshes/collision/axis_5_collision.stl
155.0 x 85.0 x 222.5

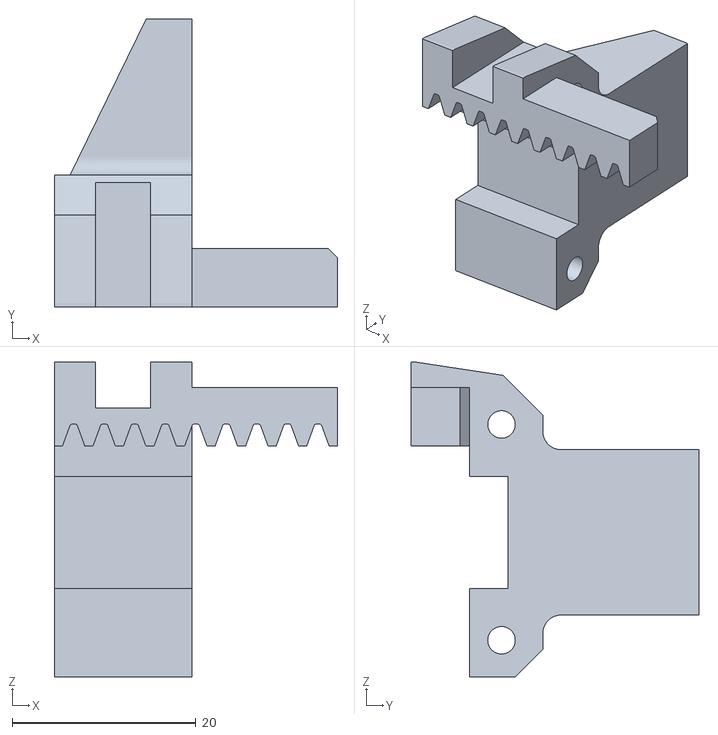
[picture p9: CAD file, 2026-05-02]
src/r0192_description/meshes/gripper/gripper_right.stl
30.9 x 31.3 x 34.3

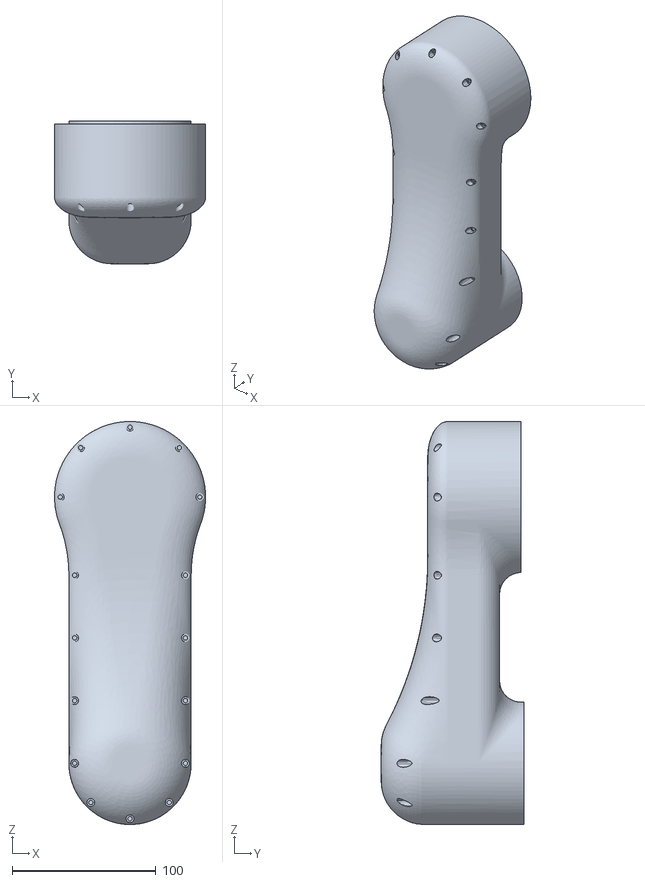
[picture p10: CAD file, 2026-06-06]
src/r0192_description/meshes/visual/axis_3.stl
105.0 x 99.1 x 280.0

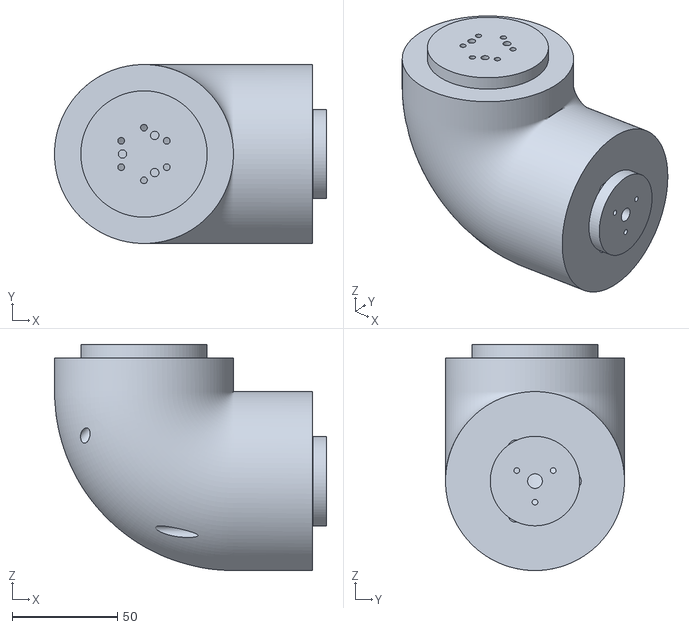
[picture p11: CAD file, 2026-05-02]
src/r0192_description/meshes/visual/original/axis_4.stl
129.2 x 85.0 x 107.4

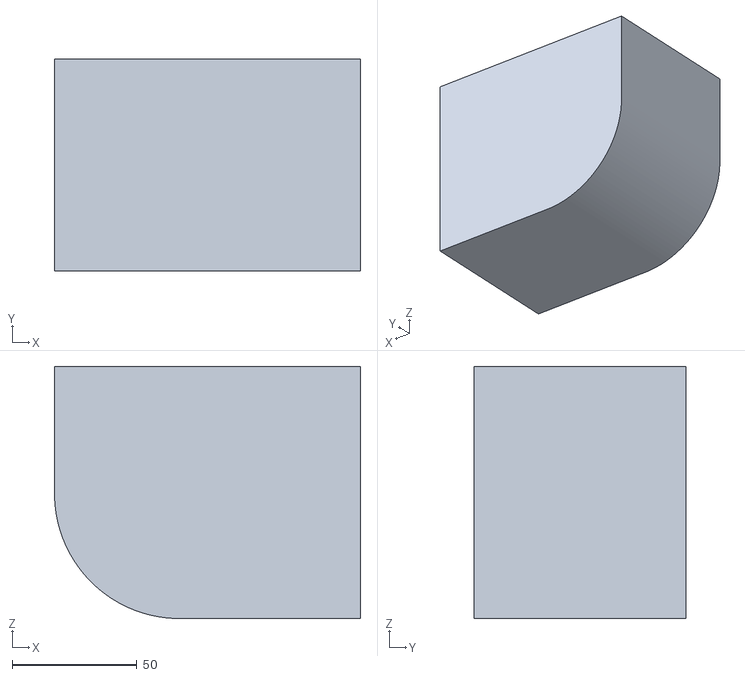
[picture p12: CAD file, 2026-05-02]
src/r0192_description/meshes/collision/axis_4_collision.stl
122.5 x 85.0 x 100.9

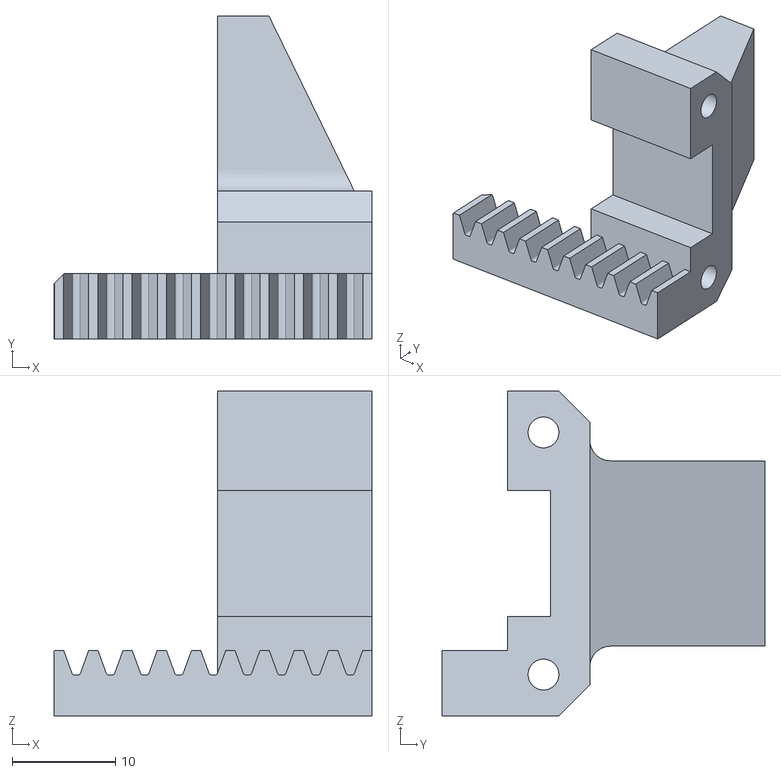
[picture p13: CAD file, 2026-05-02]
src/r0192_description/meshes/gripper/gripper_left.stl
30.9 x 31.3 x 31.5

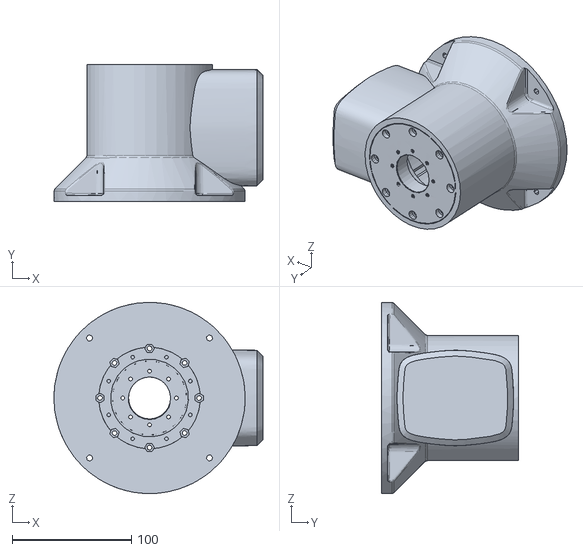
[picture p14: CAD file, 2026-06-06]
src/r0192_description/meshes/visual/axis_1.stl
175.0 x 115.0 x 160.0

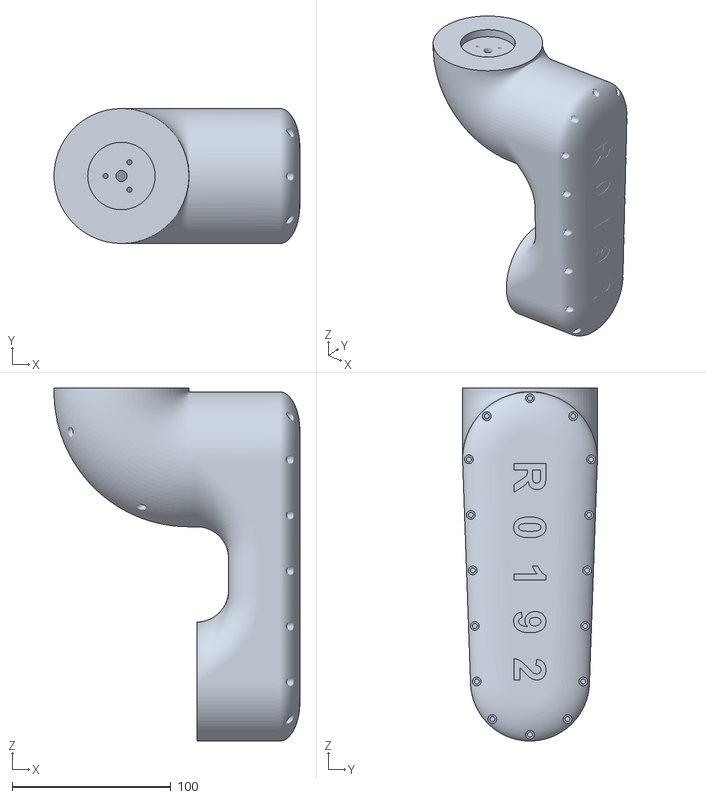
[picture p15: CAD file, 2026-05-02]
src/r0192_description/meshes/visual/original/axis_5.stl
155.0 x 85.0 x 222.5

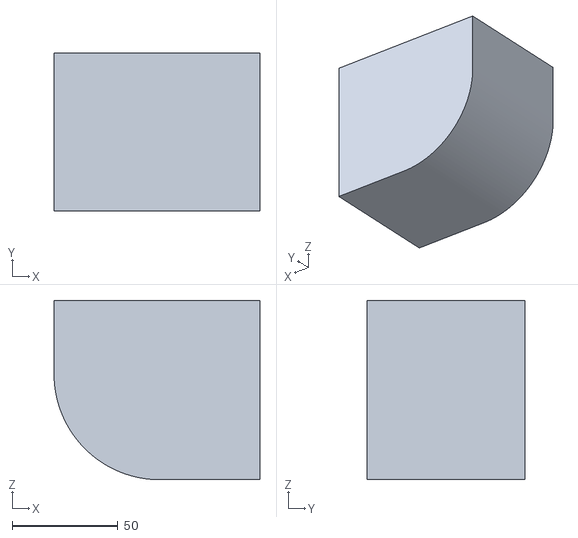
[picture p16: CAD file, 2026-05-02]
src/r0192_description/meshes/collision/axis_6_collision.stl
97.5 x 75.0 x 84.9

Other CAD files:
src/r0192_description/meshes/visual/original/axis_6.stl
src/r0192_description/meshes/visual/axis_4.stl
src/r0192_description/meshes/visual/original/flansch.stl
src/r0192_description/meshes/collision/axis_3_collision.stl
src/r0192_description/meshes/collision/axis_2_collision.stl
src/r0192_description/meshes/visual/axis_2.stl
src/r0192_description/meshes/visual/axis_5.stl
src/r0192_description/meshes/visual/original/axis_1.stl
src/r0192_description/meshes/visual/original/axis_2.stl
src/r0192_description/meshes/visual/original/axis_3.stl

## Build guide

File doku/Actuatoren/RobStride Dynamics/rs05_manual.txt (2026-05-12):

RobStride Motor User Manual

ROBSTRIDE

05

6N.M Quasi-Direct Drive Integrated Motor Module
User Manual

RobStride Dynamics
https://www.robstride.com/

RobStride Motor User Manual

RobStride Motor User Manual

RS05 instruction manual
Precautions
1.

Please use according to the working parameters specified in this article,

otherwise it may cause serious damage to the product!
2.

Do not switch the control mode when the joint is running. If you need to

switch, send the command to stop the operation before switching.
3.

Check whether the parts are in good condition before use. If the parts are

missing or damaged, contact technical support in time.
4.

Do not disassemble the motor at will, so as to avoid unrecoverable failure.

5.

Ensure that there is no short circuit when the motor is connected, and the

interface is correctly connected as required.

Legal Statement
Before using this product, please read this manual carefully and operate the
product according to the contents of this manual. If the user violates the
contents of this manual to use this product, resulting in any property damage,
personal injury accident, the company does not assume any responsibility.
Because this product is composed of many parts, do not allow children to
touch this product to avoid accidents. In order to prolong the service life of
the product, do not use this product in high temperature and high pressure
environment. This manual has been printed to the extent possible to include a
description of the functions and instructions for use. However, due to the
continuous improvement of product functions, design changes, etc., there may
still be discrepancies with the products purchased by users.
The color and appearance of this manual may differ from the actual product.
Please refer to the actual product. This manual is published by Beijing Lingfoot

1

RobStride Motor User Manual

Times Technology Co., LTD. (hereinafter referred to as Lingfoot), and Lingfoot
may at any time make necessary improvements and changes to the inaccurate
and up-to-date information in this manual, or make improvements to
procedures and/or equipment. Such changes will be uploaded to the
company's official website in electronic format. Details can be found in the
download center (www.robstride.com). All images are for reference only.
Please refer to actual objects.

After-sales Policy
The after-sales service of this product is implemented in strict accordance with
the Law of the People's Republic of China on the Protection of Consumer
Rights and Interests and the Product Quality Law of the People's Republic of
China. The service content is as follows:
1.

Warranty period and contents
a.

Users who place orders on the online channel to purchase this

product can enjoy the return service without reason within seven days
from the day after signing. When returning goods, the user must present
a valid proof of purchase and return the invoice. The user must ensure
that the returned goods maintain the original quality and function, the
appearance is intact, the trademarks and various logos of the goods
themselves and accessories are complete, and if there are gifts, they
should be returned together. If the goods are artificially damaged,
artificially disassembled, missing packaging boxes, missing parts and
accessories, they will not be returned. The logistics cost incurred during
the return shall be borne by the user (see "After-sales Service Fee
Standard"). If the user does not settle the logistics cost, it will be deducted
from the refund amount according to the actual amount incurred. Refund
the amount paid to the user within seven days from the date of receipt of
the returned item. Refund method is the same as payment method. The

2

RobStride Motor User Manual

specific arrival date may be affected by factors such as banks and
payment institutions.
b.

The warranty period of this product is 1 year.

c.

Within 7 days after the user signs for the next day, non-human

damage performance failure occurs, through the Lingzhu after-sales
service center test and confirmation, for the user to handle the return
business, the user must present a valid purchase voucher, and return the
invoice. Any freebies should be returned.
d.

From 7 days to 15 days after the user signs for the next day, non-

human damage performance failure occurs, through the Lingfoot aftersales service center test and confirmation, for the user to replace the
whole set of goods. After the replacement, the three guarantee period of
the goods themselves is recalculated.
e.

From 15 days to 365 days after the user signed the next day, after

the inspection and confirmation of the Lingfoot after-sales service center,
it is a quality fault of the product itself, and can provide free maintenance
services. The replacement of the faulty product is owned by Lingzu
Company. The product is not faulty and will be returned as is. This product
has been strictly tested after the factory, if there is a quality fault other
than the product itself, we will have the right to refuse the user's return
demand.
2.

Non-warranty regulations The following circumstances are not covered

by the warranty:
3.

Exceed the warranty period specified in the warranty terms.

4.

Failure to follow the instructions, resulting in product damage caused by

wrong use.
5.

Damage caused by improper operation, maintenance, installation,

modification, testing and other improper use.

3

RobStride Motor User Manual

6.

Non-quality failure caused by conventional mechanical loss, wear.

7.

Damage caused by abnormal working conditions, including but not

limited to falling, impact, liquid immersion, violent impact, etc.
8.

Damage caused by natural disasters (such as floods, fires, lightning strikes,

earthquakes, etc.) or incapacitated forces.
9.

Damage caused by exceeding peak torque.

10. Damage caused by exceeding peak torque.
11. Failure or damage caused by other non-product design, technology,

manufacturing, quality and other problems.
In the case of the above situation, the user must pay the cost.

4

RobStride Motor User Manual

Table of contents
Precautions ...................................................................................................................................... 1
Legal Statement ............................................................................................................................. 1
After-sales Policy ............................................................................................................................2
1. Motor specification ...................................................................................................................8
1.1. Outline and mounting dimensions ...........................................................................8
1.2. Standard service condition ......................................................................................... 8
1.3. Electrical characteristic ................................................................................................. 9
1.4. Mechanical characteristic .......................................................................................... 11
2. Driver Product Information .................................................................................................. 12
2.1. Driver product Specifications ...................................................................................12
2.2. Driver interface definition ......................................................................................... 12
2.3. Recommended driver interface brand and model ............................................ 12
3. Upper computer instructions .............................................................................................. 13
3.1. Hardware disposition ..................................................................................................13
3.2. Upper computer interface and description ......................................................... 14
3.3. Motor settings .............................................................................................................. 15
3.3.1. Motor connection settings ............................................................................ 15
3.3.2. Motor configuration module ........................................................................ 16
3.3.3. Motor upgrade module ..................................................................................16
3.3.4. Parameter settings ........................................................................................... 19
3.3.5. Oscilloscope ....................................................................................................... 30
3.3.6. can communication failure protection .......................................................31
3.3.7. Motor fault instructions ..................................................................................32
3.4. Control Demo ............................................................................................................... 34
3.4.1. Operation and control mode ........................................................................35
3.4.2. Current mode .................................................................................................... 36
3.4.3. Speed Mode .......................................................................................................37
3.4.4. Position Mode (PP) .......................................................................................... 39
3.4.5. Position Mode（CSP） ....................................................................................41
4. Driver protocol and instructions .........................................................................................43
4.1. Description of the communication protocol type ............................................. 43
4.1.1. Communication type 0: Get device ID ....................................................... 43
4.1.2. Communication Type 1: operation control mode motor control
instruction ...................................................................................................................... 44
4.1.3. Communication Type 2: motor feedback data ........................................44

5

RobStride Motor User Manual

4.1.4. Communication Type 3: Motor enabled to run ...................................... 45
4.1.5. Communication Type 4: Motor stops running ........................................ 45
4.1.6. Communication type 6: Set motor mechanical zero ............................. 45
4.1.7. Communication type 17: Single parameter read ....................................46
4.1.8. Communication type 18: Single parameter write (lost in power
failure) ............................................................................................................................. 47
4.1.9. Communication type 21: Fault feedback frame ...................................... 47
4.1.10. Communication type 22: Motor data save frame ................................ 48
4.1.11. Communication type 23: Motor baud rate modification frame (repower-on effect) .......................................................................................................... 48
4.1.12. Communication type 24: The motor actively reports frames ........... 49
4.1.13. Communication type 25: Motor protocol modification frame (repower-on effect) .......................................................................................................... 50
4.1.14. Communication type 26：Version number read frame ..................... 50
4.1.15. Read and write a single parameter list .................................................... 51
4.1.16. Read example: .................................................................................................52
4.2. Motor Function Description ..................................................................................... 53
4.2.1. Active Reporting ............................................................................................... 53
4.2.2. Zero-Point Flag (zero_sta) ..............................................................................53
4.2.3. Type 2 Update ................................................................................................... 54
4.2.4. Protocol Switching (Requires CAN adapter) ............................................ 54
4.2.5. Post-Power-Off Anti-Backdrive Protection ...............................................54
4.2.6. Zero Calibration Rules .....................................................................................55
4.2.7. Position Offset (add_offset) ...........................................................................55
4.2.8. CANopen ID ....................................................................................................... 55
4.2.9. Notes for Implementation ............................................................................. 55
4.3. Control mode instructions ........................................................................................ 56
4.3.1. Operation control mode ................................................................................ 56
4.3.2. Current mode .................................................................................................... 57
4.3.3. Velocity mode ................................................................................................... 57
4.3.4. Location Mode (CSP) .......................................................................................58
4.3.5. Location Mode (PP) ......................................................................................... 58
4.3.6. Stop running ...................................................................................................... 59
4.4. Program sample ........................................................................................................... 59
4.4.1. Motor Enabled Run frame (communication type 3) .............................. 61
4.4.2. Operation control mode Motor control instruction (communication
type 1) ............................................................................................................................. 62
4.4.3. Motor stop frame (communication type 4) ..............................................63

6

RobStride Motor User Manual

4.4.4. Motor mode parameter write command (communication type 18,
running mode switch) ................................................................................................ 64
4.4.5. Motor mode parameter write command (communication type 18,
control parameter write) ........................................................................................... 65
5. Explanation of Canopen Communication Protocol Types .......................................... 68
5.1. Introduction to CANopen Communication ..........................................................68
5.2. Canopen Protocol Message Classification ........................................................... 68
5.3. State Machine Description ........................................................................................70
5.4. Status Feedback Parameters .................................................................................... 71
5.5. Homing Mode (Zero Position Setting) .................................................................. 72
5.6. Position Mode (PP - Profile Position) .................................................................... 72
5.7. Position Mode (CSP - Cyclic Synchronous Position) ......................................... 73
5.8. Velocity Mode ...............................................................................................................74
5.9. Torque Mode ................................................................................................................ 75
5.10. Protocol Switching (Extended Frame): Switch Motor Protocol (Takes
Effect After Power Cycle) ................................................................................................... 75
6. MIT Communication Protocol Description ...................................................................... 77
6.1. Response Command 1: Data Feedback (Motor Status) ................................... 77
6.2. Response Command 2: MCU Identification .........................................................78
6.3. Command 1: Enable Motor Operation ..................................................................78
6.4. Command 2: Stop Motor Operation ......................................................................78
6.5. Command 3: MIT Dynamic Parameters ................................................................ 78
6.6. Command 4: Set Zero Position (Non-Position Mode) ......................................79
6.7. Command 5: Clear Errors & Read Fault Status ................................................... 79
6.8. Command 7: Modify Motor CAN ID ...................................................................... 79
6.9. Command 8: Change Communication Protocol (Takes Effect After Power
Cycle) ....................................................................................................................................... 80
6.10. Command 9: Modify Host CAN ID ....................................................................... 80
6.11. Command 10: Position Mode Control Command ........................................... 80
6.12. Command 11: Velocity Mode Control Command ........................................... 80
6.13. Motion Control Mode .............................................................................................. 81
6.14. Velocity Mode ............................................................................................................ 81
6.15. Position Mode (CSP - Cyclic Synchronous Position) .......................................82
7. Version History .........................................................................................................................83

7

RobStride Motor User Manual

1. Motor specification
1.1.

Outline and mounting dimensions

When fixing, the screw depth should not exceed the depth of the casing
thread

1.2.

Standard service condition

1.

Rated voltage: 48 VDC

2.

Operating voltage range: 15V-60 VDC

3.

Rated load (CW) : 1.6 N.m

4.

Operation direction: CW/CCW from the direction of the exit shaft

5.

Use posture: the direction of the exit axis is horizontal or vertical

6.

Standard operating temperature: 25±5℃

7.

Operating temperature range: -20 ~ 50℃

8.

Standard operating humidity: 65%

9.

Humidity range: 5 ~ 85%, no condensation

10. Storage temperature range: -30 ~ 70℃
11. Insulation Class: Class B

8

RobStride Motor User Manual

1.3.

Electrical characteristic

1.

No load speed: 480 rpm±10%

2.

No-load current：0.14 Arms ±10%

3.

Rated load: 1.6 N.m

4.

Rated load speed: 100rpm±10%

5.

Rated load phase current (peak) : 2.4Apk±10%

6.

Peak load: 5.5 N.m

7.

Maximum load phase current (peak) : 11Apk±10%

8.

Insulation resistance/stator winding: DC 500VAC, 100M Ohms

9.

High voltage/stator and housing: 600 VAC, 1s, 2mA

10. Motor back potential: 7.4Vrms/kRPM±10%
11. Torque constant: 0.94N.m/Arms
12. T-N curve (48V)

13. Maximum overload curve

Test conditions: Ambient temperature: 25℃

9

RobStride Motor User Manual

Winding limit temperature: 135℃ (this is the constraint temperature, the
actual is 180 degrees)
Speed: 100rpm

Test data

14. Thermal testing Test Conditions:
Heat sink size: 70mm x 70mm
Ambient temperature: 25℃
Winding protection temperature: 145℃
Test condition 1: Motor rotates at 100rpm, monitor the motor thermistor
temperature, and record the time it takes for the motor thermistor temperature to

10

RobStride Motor User Manual

rise from 25℃ to 145℃.

Motor locked-rotor condition 2: According to the current formula, the average
phase current during locked-rotor is approximately 1.414 times that of rotation.
This is used to obtain the overload time table for the locked-rotor condition.

1.4.

Mechanical characteristic

1.

Weight: 191g±3g

2.

Number of poles: 20

3.

Phase number: 3 phases

4.

Drive mode: FOC

5.

Deceleration ratio: 7.75:1

11

RobStride Motor User Manual

2. Driver Product Information
2.1.

Driver product Specifications
project

data

The rated working voltage

48VDC

The maximum allowable voltage

60VDC

Rated working phase current

2.4Apk

Maximum allowable phase current

11.0Apk

Standby power

≤18mA

CAN bus bit rate

1Mbps

Dimensions

Φ41mm

Working environment temperature

-20℃ to 50℃

The maximum allowable temperature of the control board

135℃

encoder resolution

14bit (absolute turn)

2.2.

Driver interface definition

2.3.

Recommended driver interface brand and
model

board end model

brand manufacturer

line end model

brand manufacturer

XT30PB(2+2)-M.G.B

AMASS (Ams)

XT30(2+2)-F.G.B

AMASS (Ams)

12

RobStride Motor User Manual

3. Upper computer instructions
Please go to www.robstride.com website download center

3.1.

Hardware disposition

The articulated motor uses the CAN communication mode and has two
communication cables. It is connected to the debugger through the can to
USB tool. The debugger needs to be installed with the ch340 driver in advance
and works in AT mode by default.
It should be noted that we are based on the specific can to USB tool
development of the debugger, so we need to use our recommended serial
port tool to debug the debugger, if you want to transplant to other debugger
platform can refer to the third chapter of the instructions for development.
The CAN to USB tool is recommended to use the official USB-CAN module of
Lingzu Times. The frame header of the corresponding serial port protocol is 41
54, and the frame tail is 0D 0A.
When using the CAN-to-USB module, pay attention to the settings of the DIP
switches on the module: When DIP switch 1 is in the ON position, the module
enters Boot mode and cannot establish a connection with the host computer.
When DIP switch 2 is in the ON position, a 120Ω terminal resistor is connected
to the module port, allowing normal communication with the host computer.

13

RobStride Motor User Manual

3.2.

Upper computer interface and description

Mainly includes:
A. Motor Connection Module
•

Refreshing the Serial Port

•

Opening the Serial Port

•

Testing the Device

B. Motor Configuration Module
•

Starting the Upgrade

•

Opening a File

•

Starting the Upgrade

•

Modifying the Motor CAN ID

•

Setting the Motor's Mechanical Zero Position

C. Motor Upgrade Module
•

Magnetic Encoder Calibration

•

Motor Active Reporting Switch

14

RobStride Motor User Manual

•

Setting the Motor Active Reporting Time

•

Modifying the Motor CAN ID

•

Setting the Motor's Mechanical Zero Position

D. Motor Main Interface
•

Parameter Settings

•

Motor Oscilloscope

E. Run and Debug Area
•

Parameter Debugging Buttons

•

Motor Mode Configuration and Parameter Modification

•

Sine Signal Testing

3.3.

Motor settings

3.3.1. Motor connection settings

Connect the CAN to USB tool (install the ch340 driver, which works in AT
mode by default), click Refresh Serial Port, open the serial port, and click
Detect Device to detect the corresponding motor. The green text below is the
motor type.

15

RobStride Motor User Manual

3.3.2. Motor configuration module

1.

Recalibrate the motor magnetic encoder. Reinstalling the motor board

and motor, or reconnecting the motor's three-phase wiring requires
recalibrating the magnetic encoder.
2.

Enable active motor reporting. Click Start Reporting to enable active

motor reporting in communication type 2. You can set the interval below, with
a minimum of 10ms.
3.

Set ID: Set the motor's CAN ID.

4.

Set Zero Position: Set the current position to 0.

3.3.3. Motor upgrade module
1.

1. Click to open the file and select the firmware to upgrade. The rs-0x in

the firmware name is the selected motor type.

16

RobStride Motor User Manual

2.

Click Start Upgrade, and the motor will enter the upgrade preparation

stage.

3.

When the green text "Device has entered upgrade mode" pops up, click

to start the upgrade

17

RobStride Motor User Manual

4.

When the green text "Upgrade Successfully" pops up, the upgrade is

complete.

If the green progress bar gets stuck halfway through the upgrade, you can
click to stop the upgrade, or re-power on and re-enter the upgrade process.
The internal program of the motor will not be lost after the upgrade fails.
Please check whether the communication environment is good before
upgrading again.

18

RobStride Motor User Manual

3.3.4. Parameter settings

After successfully connecting to the motor,
1.

Click Refresh Parameter Table. "Updated Parameter Table Successfully"

will appear at the top, indicating that the motor parameters have been
successfully read (Note: The parameter table must be configured while the
motor is in standby mode. If the motor is running, the parameter table refresh
cannot be performed). The interface will display the motor's parameters.
Parameters in blue are stored internally in the motor and can be modified in
the Current Value field following the corresponding parameter.
2.

Click Read Parameters to upload the motor parameters to the debugger.

Parameters in light blue are observed parameters, which are collected and can
be observed in real time.
3.

Click Write Parameters to download the debugger parameters to the

motor.
4.

Click Restore Factory to restore the motor's default parameters for the

latest firmware.

19

RobStride Motor User Manual

5.

Click Export to export the current motor parameters in the parameter

table.
6.

Click Open Multi-Device Connection to connect the host computer to

multiple motors. Note that because the parameter interfaces for different
motor types vary, multi-device connection is only used for upgrades. After
upgrading and debugging the motor, close multi-device connection and
search for the motor again.
Note: Please do not change the torque limit, protection temperature and
overtemperature time of the motor. Our company will not bear any legal
responsibility for any damage to human body or irreversible damage to
joints caused by illegal operation of this product.

parame

functio

name

n code

ter
type

0X0000

Name

String

0X0001

BarCode

String

0X1000
0X1001
0X1002

BootCodeVer
sion
BootBuildDat
e
BootBuildTim
e

String
String
String

attribut

Maxim

Minim

um

um

value

value

e
Read/W

Current
value
(for

Remark

reference)
ÿÿÿÿÿÿÿÿÿÿÿ

rite

ÿÿÿÿÿ

Read/W

ÿÿÿÿÿÿÿÿÿÿÿ

rite

ÿÿÿÿÿ

Read

0.1.5

only
Read

Mar 16

only

2022

Read

20:22:09

only

Motor
0X1003

AppCodeVer
sion

String

Read

0.0.0.1

only

program
version
number

0X1004
0X1005
0X1006

AppGitVersio
n
AppBuildDat
e
AppBuildTim
e

String
String
String

Read

7b844b0fM

only
Read

Apr 14 2022

only
Read

20:30:22

only

20

RobStride Motor User Manual

parame

functio

name

n code

0X1007

ter
type

AppCodeNa
me

String

0X2000

echoPara1

uint16

0X2001

echoPara2

uint16

0X2002

echoPara3

uint16

0X2003

echoPara4

uint16

0X2004

echoFreHz

uint32

attribut

Maxim

Minim

um

um

value

value

e

Current
value
(for
reference)

Read

Lingzu_mot

only

or

disposit
ion
disposit
ion
disposit
ion
disposit
ion
Read/W
rite

Remark

74

5

5

74

5

5

74

5

5

74

5

5

10000

1

500
Motor

0X2005

MechOffset

float

Settings

7

-7

4.619583

magnetic
encoder
Angle offset

0X2006

MechPos_init

float

0X2007

limit_torque

float

Read/W
rite
Read/W
rite

50

-50

4.52

17

0

17

Reserved
parameter
Torque
limitation
Weak

0X2008

I_FW_MAX

float

magnetic

Read/W

33

rite

0

0

current
value,
default 0

0X2009

motor_baud

uint8

Settings

20

0

1

0X200a

CAN_ID

uint8

Settings

127

0

1

uint8

Settings

127

0

0

0X200b

CAN_MASTE
R

Baud rate
flag bit
id of this
object
can host id
can timeout

0X200c

CAN_TIMEO
UT

uint32

Read/W
rite

100000

0

0

threshold.
The default
value is 0

0X200d

status2

int16

0X200e

status3

uint32

Read/W

1500

0

800

100000

1000

20000

rite
Read/W

21

Reserved
parameter
Reserved

RobStride Motor User Manual

parame

functio

name

n code

ter
type

attribut

Maxim

Minim

um

um

value

value

e
rite

0X200f

status1

float

0X2010

Status6

uint8

0X2011

cur_filt_gain

float

0X2012

cur_kp

float

0X2013

cur_ki

float

0X2014

spd_kp

float

0X2015

spd_ki

float

0X2016

loc_kp

float

0X2017

0X2018

spd_filt_gain

limit_spd

float

float

Current
value
(for
reference)

0

Read/W
rite
Read/W
rite

Remark

parameter

64

1

7.75

1

0

1

Reserved
parameter
Reserved
parameter
Current

Read/W

1

rite

0

0.9

filtering
parameter

Read/W
rite
Read/W
rite
Read/W
rite
Read/W
rite
Read/W
rite

200

0

0.025

Current kp

200

0

0.0258

Current ki

200

0

2

Velocity kp

200

0

0.021

Speed ki

200

0

30

Position kp
Velocity

Read/W

1

rite

0

0.1

filter
parameter
Location

Read/W

200

rite

0

2

mode
speed limit
Position,

0X2019

limit_cur

float

Read/W

23

rite

0

23

Velocity
mode
current limit

0X201a
0X201b

0X201c

0X201d
0X201e

loc_ref_filt_ga
in
limit_loc
position_offs
et
chasu_angle_
offset
spd_step_val

float
float

float

float
float

Read/W
rite
Read/W
rite

100

0

0

100

0

0

Reserved
parameter
Reserved
parameter
High speed

Read/W

27

rite

0

0

segment
offset

Read/W
rite
Read/W

22

27

0

150

0

0

The low end
is offset
Velocity-

RobStride Motor User Manual

parame

functio

name

n code

ter
type

ue

attribut

Maxim

Minim

um

um

value

value

e

Current
value
(for

Remark

reference)

rite

mode
acceleration

0X201f

vel_max

float

0X2020

acc_set

float

0X2021

zero_sta

float

0x2022

protocol_1

uint8

0X3000

timeUse0

uint16

0X3001

timeUse1

uint16

0X3002

timeUse2

uint16

0X3003

timeUse3

uint16

Read/W
rite
Read/W
rite
Read/W
rite
Read/W

20

0

1000

0

100

0

PP mode
speed
PP mode
acceleration
0
0

rite
Read

Zero marker
Protocol
flag

5

only
Read

0

only
Read

10

only
Read

0

only

Magnetic
0X3004

encoderRaw

int16

Read

11396

only

encoder
sampling
value
mcu

0X3005

mcuTemp

int16

Read

337

only

internal
temperatur
e, *10

0X3006

0X3007

motorTemp

vBus(mv)

int16

uint16

Motor ntc

Read

333

only

temperatur
e, *10

Read

24195

only

Bus voltage
adc

0X3008

adc1Offset

int32

sampling

Read

2084

only

channel 1
Zero
current bias

0X3009

adc2Offset

int32

Read

2084

only

23

adc
sampling

RobStride Motor User Manual

functio
n code

parame
name

ter
type

attribut

Maxim

Minim

um

um

value

value

e

Current
value

Remark

(for
reference)

channel 2
Zero
current bias
0X300a

0X300b

0X300c

0X300d

0X300e

adc1Raw

adc2Raw

VBUS

cmdId

cmdIq

uint16

uint16

float

float

float

adc

Read

1232

only

sampling
value 1
adc

Read

1212

only

sampling
value 2

Read

36

only

Bus voltage
V
id ring

Read

0

only

instruction,
A
iq ring

Read

0

only

command,
A
Position

0X300f

cmdlocref

float

Read

0

only

loop
command,
rad

0X3010

0X3011

0X3012

0X3013

0X3014

0X3015

cmdspdref

cmdTorque

cmdPos

cmdVel

rotation

modPos

float

float

float

float

int16

float

Speed loop

Read

0

only

command,
rad/s
Torque

Read

0

only

instruction,
nm
mit Protocol

Read

0

only

Angle
instruction
mit Protocol

Read

0

only

Speed
instruction

Read

1

only

Number of
turns
Motor

Read

4.363409

only

uncounted
coil

24

RobStride Motor User Manual

parame

functio

name

n code

ter
type

attribut

Maxim

Minim

um

um

value

value

e

Current
value
(for

Remark

reference)
mechanical
Angle, rad
Load end

0X3016

mechPos

float

Read

0.777679

only

loop
mechanical
Angle, rad

0X3017

mechVel

float

0X3018

elecPos

float

0X3019

ia

float

0X301a

ib

float

0X301b

ic

float

0X301c

timeout

uint32

0X301d

phaseOrder

uint8

0X301e

iqf

float

0X301f

boardTemp

int16

0X3020

iq

float

0X3021

id

float

0X3022

faultSta

uint32

0X3023

warnSta

uint32

0X3024
0X3025

drv_fault
drv_temp

uint16
int16

Read

0.036618

only
Read

4.714761

only
Read

0

only
Read

0

only
Read

0

only

Load speed:
rad/s
Electrical
Angle
U-wire
current, A
V-wire
current, A
W-wire
current, A
Timeout

Read

31600

only

counter
value

Read

0

only
Read

0

only

Directional
marking
iq filter
value，A
Plate

Read

359

only

temperatur
e，*10

Read

0

only
Read

0

only
Read

0

only
Read

0

only

iq Original
value，A
id Original
value，A
Fault status
value
Warning
status value
The driver

Read

0

only

chip fault
value is 1

Read

48

25

The driver

RobStride Motor User Manual

parame

functio

name

n code

ter
type

attribut

Maxim

Minim

um

um

value

value

e

Current
value

Remark

(for
reference)

only

chip fault
value is 2

0X3026

Uq

float

0X3027

Ud

float

Read

0

only
Read

0

only

Q-axis
voltage
D-axis
voltage
The duty

0X3028

dtc_u

float

Read

0

only

cycle of the
U-phase
output
The duty

0X3029

dtc_v

float

Read

0

only

cycle of the
V-phase
output
The duty

0X302a

dtc_w

float

Read

0

only

cycle of the
W-phase
output

0X302b

0X302c

0X302d

v_bus

torque_fdb

rated_i

float

float

float

Read

24.195

only

Vbus in the
closed loop
Torque

Read

0

only

feedback
value，nm
Rated

Read

8

only

current of
motor
The motor

0X302e

limit_i

float

Read

27

only

limits the
maximum
current

0X302f

spd_ref

float

Motor

Read

0

only

speed
expectation
Motor

0X3030

spd_reff

float

Read

0

only

speed
expectation
2

0X3031

zero_fault

float

Read

0

26

Motor

RobStride Motor User Manual

parame

functio

name

n code

ter
type

attribut

Maxim

Minim

um

um

value

value

e

Current
value
(for

Remark

reference)

only

position
determinati
on
parameters
Motor

0X3032

chasu_coder_
raw

float

position

Read

0

only

determinati
on
parameters
Motor

0X3033

chasu_angle

float

position

Read

0

only

determinati
on
parameters
Motor

0X3034

as_angle

float

position

Read

0

only

determinati
on
parameters

0X3035

cs_angle

float

Read
only
Motor

0X3036

vel_max

float

position

Read

0

only

determinati
on
parameters
Motor

0X3037

judge

float

position

Read

0

only

determinati
on
parameters

0X3038

fault1

uint32

0X3039

fault2

uint32

0X303a

fault3

uint32

0X303b

fault4

uint32

Read
only
Read
only
Read
only
Read

27

0

Log failure

0

Log failure

0

Log failure

0

Log failure

RobStride Motor User Manual

parame

functio

name

n code

ter
type

attribut

Maxim

Minim

um

um

value

value

e

Current
value
(for

Remark

reference)

only
0X303c

fault5

uint32

0X303d

fault6

uint32

0X303e

fault7

uint32

0X303f

fault8

uint32

0X3040

ElecOffset

float

0X3041

mcOverTemp

int16

0X3042

Kt_Nm/Amp

float

0X3043

Tqcali_Type

uint8

Read
only
Read
only
Read
only
Read
only
Read

0

Log failure

0

Log failure

0

Log failure

0

Log failure

0

only

electrical
Angle offset
Overtemper

Read

0

only

ature
threshold

Read

0

only
Read

0

only

Moment
coefficient
Motor type
Motor

0X3044

low_position

float

position

Read

0

only

determinati
on
parameters

0X3045

theta_mech_
1

float

Type 2 Low

Read

0

only

speed
Angle
Motor

0X3046

instep

float

Read

0

only

protection
decision
parameters

0X3047

position

float

Read

18.243250

only

Initial
position
Motor

0X3048

chasu_angle_
init

float

position

Read

0.598253

only

determinat
ion
parameter

28

RobStride Motor User Manual

parame

functio

name

n code

ter
type

attribut

Maxim

Minim

um

um

value

value

e

Current
value

Remark

(for
reference)

s
Motor
position
0X3049

chasu_angle_
out

float

Read

18.545835

only

determinat
ion
parameter
s
Motor
position

0X304A

motormechin
it

float

Read

18.243250

only

determinat
ion
parameter
s
Motor
position

0X304B

mech_angle_i
nit2

float

Read

2.353968

only

determinat
ion
parameter
s
Motor
position

0X304C

mech_angle_
rotat

int16

Read

determinat

only

ion
parameter
s

0X304D

0X304E

pos_cnt1

H’

uint16

uint8

System

Read

0

only

parameter
s
System

Read

72

only

parameter
s

29

RobStride Motor User Manual

3.3.5. Oscilloscope
The interface supports viewing and observing the graph generated by realtime data, including motor Id/Iq current, temperature, real-time speed at the
output end, rotor (encoder) position, output end position, etc.
Click on the oscilloscope module in the analysis module, select the
appropriate parameters in the channel (parameter meaning can be referred to
the parameter table), set the output frequency, click on the start plot to
observe the data graph, stop the plot to stop the observation graph.

The command sent is in the communication command box below

30

RobStride Motor User Manual

Communication box instruction example:
41 54 90 07 e8 0c 08 05 70 00 00 01 00 00 00 0d 0a
The meaning is as follows
41 54

90 07 e8 0c

8

05 70 00 00 01 00 00

0d 0a

00
frame header

Number of data

extended

bits

frame

data frame

frame tail

The translation of extended frame canid into real canid requires the following
transformations:
90 07 e8 0c converts to binary as 1001 0000 0000 0111 1110 1000 0000 1100,
remove the 100 on the right and it becomes 1 0010 0000 0000 1111 1101
0000 0001, convert it to hexadecimal, It is 12 00 FD 01. According to the
communication protocol, the meaning is as follows:
12 in hexadecimal

0

FD

1

Communication type 18 (in decimal base)

No meaning

host id

motor canid

3.3.6. can communication failure protection
When the value of CAN_TIMEOUT is 0, this function is disabled

31

RobStride Motor User Manual

When the CAN_TIMEOUT value is non-0, when the motor does not receive the
can command within a certain period of time, the motor enters the reset mode,
and 20000 is 1s

3.3.7. Motor fault instructions
Function code 0x3022 indicates the fault code, where
bit14:motor blocking overload algorithm protection
bit7: Encoder uncalibrated: Motor uncalibrated encoder
bit3: Overvoltage fault: the motor voltage exceeds the protection voltage by
60V
bit2: Undervoltage fault: the motor voltage is lower than the protection
voltage of 12V
bit1: Driver chip failure: Motor driver chip failure reported
bit0: Motor overtemperature fault: motor thermistor temperature exceeds 135
degrees
Function code 0x3024 is driver chip fault code 1. The specific faults are as
follows

Function code 0x3025 is driver chip fault code 2. The specific faults are as
follows

32

RobStride Motor User Manual

33

RobStride Motor User Manual

3.4.

Control Demo

34

RobStride Motor User Manual

Jog Run
Click JOG +/- to run the motor forward and reverse at a speed of 1 rad/s.
Control Mode Switching
Select the desired control mode in the command box to the right of the run
mode.

3.4.1. Operation and control mode

1.

Switch the control mode to operation mode.

2.

The motor starts running and enters motor_mode.

3.

Set five parameter values and click Start or Send continuously. The motor

will return feedback frames and run according to the target command.
4.

Click Stop to stop the motor and terminate the continuous sending of

commands.

35

RobStride Motor User Manual

3.4.2. Current mode

1.

Switch the control mode to current mode.

2.

The motor starts running and enters motor_mode.

3.

Set the current command value for Iq Command 1 (A). Click the >>

button on the right. The motor will follow the current command.
4.

Click Stop to stop the motor.

Motor Current Sine Test

36

RobStride Motor User Manual

1.

Switch the control mode to current mode.

2.

The motor starts running and enters motor_mode.

3.

Set the amplitude and frequency, click OK, and then click Start. The

corresponding mode target command will be planned according to the sine
law.
4.

Click Stop to stop the motor.

3.4.3. Speed Mode

1.

Switch the control mode to speed mode.

2.

The motor starts running and enters motor_mode.

3.

First, set the current limit (maximum phase current) and speed step value

(motor acceleration). If no settings are made, the motor will operate at the
default values. Finally, set the speed command (target speed). The motor will

37

RobStride Motor User Manual

follow the command.
4.

Click Stop to stop the motor.

Motor Speed Sine Test
1.

Switch the control mode to speed mode.

2.

The motor starts running and enters motor_mode.

3.

Set the amplitude and frequency, click OK, and then click Start. The

corresponding mode target command will be planned according to the sine
law.
4.

Click Stop to stop the motor.

38

RobStride Motor User Manual

3.4.4. Position Mode (PP)

1.

Switch the control mode to interpolation position mode.

2.

Start the motor and enter motor_mode.

3.

First, set the speed and acceleration. If not set, the motor will operate at

the default values. Finally, set the position command (target position). The
motor will follow the command.
4.

Set the speed to 0 to stop the motor at the current position. To continue

operation, re-issue the speed and position.
5.

Click Stop to stop the motor.

39

RobStride Motor User Manual

Motor Position Sine Test
1.

Switch the control mode to interpolation position mode.

2.

Start the motor and enter motor_mode.

3.

Set the amplitude and frequency, click OK, and then click Start. The

corresponding mode target command will be planned according to the sine
law.
4.

Click Stop to stop the motor.

40

RobStride Motor User Manual

3.4.5. Position Mode（CSP）

1.

Switch the control mode to position mode.

2.

The motor starts running and enters motor_mode.

3.

Set the speed first. If no speed setting is made, the motor will run at the

default value. Finally, set the position command (target position). The motor
will follow the command.
4.

Click Stop to stop the motor.

41

RobStride Motor User Manual

Motor position sinusoidal test
1.

Switch the control mode to position mode.

2.

The motor starts running and enters motor_mode.

3.

Set the amplitude and frequency, click OK, and then click Start. The

corresponding mode target command is then sinusoidally planned.
4.

Click Stop to stop the motor.

42

RobStride Motor User Manual

4. Driver protocol and instructions
The motor communication is the CAN 2.0 communication interface, the baud
rate is 1Mbps, and the extended frame format is adopted as follows:
data field

29-bit ID

8Byte data
field

Size

Bit28~bit24

bit23~8

bit7~0

Byte0~Byte7

Description

Communication type

data area 2

Destination address

data area 1

The control modes supported by the motor include:
•

Operation control mode: set 5 parameters of motor operation control;

•

Current mode: the specified Iq current of the given motor;

•

Velocity mode: the specified running speed of the given motor;

•

Position mode: Given the specified position of the motor, the motor will

run to the specified position;

4.1.

Description of the communication protocol
type

4.1.1. Communication type 0: Get device ID
Gets the device's ID and 64-bit MCU unique identifier
data field

29-bit ID

8Byte data
field

Size

Bit28~bit24

bit23~8

bit7~0

Byte0~Byte7

Description

0x0

bit15~8: identifies host

target motor

0

CAN_ID

CAN_ID

Reply frame:
data field

29-bit ID

8Byte data field

Size

Bit28~bit24

bit23~8

bit7~0

Byte0~Byte7

Description

0x0

target motor CAN_ID

0XFE

64-bit MCU unique identifier

43

RobStride Motor User Manual

4.1.2. Communication Type 1: operation control
mode motor control instruction
Data field

29 bit ID

8Byte data field

Size

Bit28~bit24

bit23~8

bit7~0

Byte0~Byte7

description

0x1

Byte2: Torque

target

Byte0~1: target Angle [0~65535]

(0~65535)

motor

corresponds to (-4π~4π)

corresponds to

CAN

Byte2~3: Target angular velocity

(-

_ID

[0~65535] corresponds to (-

5.5Nm~5.5Nm)

50rad/s~50rad/s)
Byte4~5: Kp [0~65535]
corresponds to (0.0~500.0)
Byte6~7: Kd [0 to 65535]
corresponds to the above data (0.0
to 5.0). After the conversion, the
high byte is in front and the low
byte is in

Response frame: Response motor feedback frame (see communication type 2)

4.1.3. Communication Type 2: motor feedback data
Data field

29 bit ID

8Byte data field

Size

Bit28~bit24

bit23~8

bit7~0

Byte0~Byte7

Description

0x2

Bit8~Bit15: CAN ID

host

Byte0~1: The current Angle

of the current

CAN

[0~65535] Corresponding to (-4

motor

_ID

π~4π)

bit21~16: fault

Byte2~3: Current angular

information (0

velocity [0~65535] corresponds

none 1 has)

to (-50rad/s~50rad/s)

bit21: uncalibrated

Byte4~5: Current torque

bit20: Uncalibrated

[0~65535] corresponds to (-

bit20: Gridlock

5.5Nm~5.5Nm)

overload fault

Byte6~7: Current temperature:

bit19: magnetic

Temp(Celsius) *10 If the value is

coding fault

higher than 10, the high byte is

bit18:

first and the low byte is last

overtemperature
bit17: Three-phase
overcurrent fault
bit16:

44

RobStride Motor User Manual

undervoltage fault
bit22~23:
Mode status 0:
Reset mode [reset]
1: Cali mode
[calibration]
2: Motor mode
[Run]

4.1.4. Communication Type 3: Motor enabled to
run
data field

29-bit ID

8Byte data
field

Size

Bit28~bit24

bit23~8

bit7~0

Byte0~Byte7

Description

0x3

bit15~8: identifies the

and target motor

main CAN_ID

CAN_ID

Response frame: Response motor feedback frame (see communication type 2)

4.1.5. Communication Type 4: Motor stops running
data field

29-bit ID

8Byte data field

Size

Bit28~bit24

bit23~8

bit7~0

Byte0~Byte7

description

0x4

bit15~8: used

target

When the motor is running

to identify the

motor

normally, 0 must be cleared in

main CAN_ID

CAN_ID

the data field. Byte[0]=1: The
fault is cleared.

Response frame: Response motor feedback frame (see communication type 2)

4.1.6. Communication

type

6:

Set

motor

mechanical zero
data field

29-bit ID

8Byte data field

Size

Bit28~bit24

bit23~8

bit7~0

Byte0~Byte7

description

0x6

bit15~8: Identifies the

and target

Byte[0]=1

main CAN_ID

motor CAN_ID

Response frame: Response motor feedback frame (see communication type 2)

45

RobStride Motor User Manual

Communication type 7: Set motor CAN_ID
Change the current motor CAN_ID, effective immediately.
data field

29-bit ID

8Byte data
field

Size

Bit28~bit24

bit23~8

bit7~0

description

0x7

bit15~8: used to identify main

Target

CAN_ID Bit16~23: preset CAN_ID

motor

Byte0~Byte7

CAN_ID

Answer frame: Answer motor broadcast frame (see communication type 0)

4.1.7. Communication type 17: Single parameter
read
Data field

29 bit ID

8Byte data field

Size

Bit28~bit24

bit23~8

bit7~0

Byte0~Byte7

description

0x11

bit15~8:

target

Byte0~1: index. For details, see the

Used to

motor

readability parameter table below

identify the

CAN_ID

Byte2~3:00 Byte4~7: In data above

main

00, the low byte is first and the high

CAN_ID

byte is second (

Reply frame:
Data field

29 bit ID

8Byte data
field

Size

Bit28~bit24

bit23~8

bit7~0

description

0x11

bit15~8: indicates

Byte0~1: Byte2~3:00

that the master

Byte4~7:Parameter

CAN_ID

data. 1 byte of data

Bit23~16:00

above Byte4 is

indicates that the

preceded by low

master CAN_ID is

bytes and followed

successfully read. 01

by high bytes at

indicates that the
master can_ID

46

Byte0~Byte7

RobStride Motor User Manual

4.1.8. Communication type 18: Single parameter
write (lost in power failure)
With type 22, the parameter starting with function code 0x20 of the parameter
table in the upper computer module can be saved
Data field

29 bit ID

8Byte data field

Size

Bit28~bit24

bit23~8

bit7~0

Byte0~Byte7

description

0x12

bit15~8:

target

Byte0~1: index. For details, see the

Used to

motor

readability parameter table below

identify the

CAN_ID

Byte2~3: 00

main

Byte4~7: Parameter data In the

CAN_ID

preceding data, the low byte is in the
front and the high byte is in the rear

Response frame: Response motor feedback frame (see communication type 2)

4.1.9. Communication

type

21:

Fault

feedback

frame
data field

29-bit ID

8Byte data field

Size

Bit28~bit24

bit23~8

bit7~0

Byte0~Byte7

description

0x15

bit15~8:

identifies

Byte0~3: fault value (non-0: faulty; 0:

motor

the main

faulty). Normal)

CAN_ID

CAN_ID

Bit 16: A-phase current sampling
overcurrent
Bit 14: Motor stall overload algorithm
protection
Bit 9: Position initialization fault
Bit 8: Hardware identification fault
Bit 7: Encoder uncalibrated: Motor
encoder not calibrated
Bit 5: C-phase current sampling
overcurrent
Bit 4: B-phase current sampling
overcurrent
bit3: overvoltage fault
bit2: undervoltage fault
bit1: driver chip fault
bit0: motor overtemperature fault,

47

RobStride Motor User Manual

Default 135 ° C
Byte4~7: warning Value
bit0: motor overtemperature warning,
the default is 135 ° c

4.1.10.

Communication type 22: Motor data save

frame
data field

29-bit ID

8Byte data field

Size

Bit28~bit24

bit23~8

bit7~0

Byte0~Byte7

Description

0x16

bit15~8: identifies the

and target

01 02 03 04 05

main CAN_ID

motor CAN_ID

06 07 08

Response frame: Response motor feedback frame (see communication type 2)

4.1.11.

Communication type 23: Motor baud rate

modification frame (re-power-on effect)
Data field

29 bit ID

8Byte data field

Size

Bit28~bit24

bit23~8

bit7~0

Byte0~Byte7

description

0x17

bit15~8:

target

01 02 03 04 05 06 F_CMD

used to

motor

Among them, the F_CMD byte is the

identify the

CAN_ID

motor baud rate Among them,

main

01 is 1M

CAN_ID

02 is 500K
03 is 250K
04 is 125K

Response frame: Response motor feedback frame (see communication type 0)

48

RobStride Motor User Manual

4.1.12.

Communication

type

24:

The

motor

actively reports frames
data field

29-bit ID

8Byte data field

Size

Bit28~bit24

bit23~8

bit7~0

Byte0~Byte7

description

0x18

bit15~8:

target

01 02 03 04 05 06 F_CMD

identifies

motor

Among them, the F_CMD byte is the

the main

CAN_ID

motor reporting switch 00 is to

CAN_ID

disable active reporting (default)

01

To enable active reporting, the default
reporting interval is 10ms

Response frame:
data field

29 位 ID

8Byte data field

Size

Bit28~bit24

bit23~8

bit7~0

Byte0~Byte7

description

0x18

Bit8~Bit15: CAN ID of the

target

Byte0~1: The

current motor

motor

current Angle

CAN_ID

[0~65535]

bit21~16:

fault information (0 none 1 has)
bit21: uncalibrated

Corresponding to

bit20: Uncalibrated

(-4π~4π)

bit20: Gridlock overload fault

Byte2~3: Current

bit19: magnetic coding fault

angular velocity

bit18:overtemperature

[0~65535]

bit17: Three-phase overcurrent

corresponds to (-

fault

50rad/s~50rad/s)

bit16: undervoltage fault

Byte4~5: Current

bit22~23: Mode status

torque [0~65535]

0: Reset mode [reset]

corresponds to (-

1: Cali mode [calibration]

5.5Nm~5.5Nm)

2: Motor mode [Run]

Byte6~7: Current
temperature:
Temp(Celsius) *10
If the value is
higher than 10, the
high byte is first
and the low byte is
last

49

RobStride Motor User Manual

4.1.13.

Communication type 25: Motor protocol

modification frame (re-power-on effect)
Data field

29 bit ID

8Byte data field

Size

Bit28~bit24

bit23~8

bit7~0

Byte0~Byte7

description

0x19

bit15~8:

target

01 02 03 04 05 06 F_CMD

used to

motor

Among them, the F_CMD byte is the

identify the

CAN_ID

motor protocol type Among them,

main

0 is a private protocol (default)

CAN_ID

1 is the Canopen protocol
2 is the MIT protocol

Response frame: Response motor feedback frame (see communication type 0)

4.1.14.

Communication type 26：Version number

read frame
Data field

29 bit ID

8Byte data field

Size

Bit28~bit24

bit23~8

bit7~0

Byte0~Byte7

description

0x4

bit15~8: used to

target motor

Byte[0]=0x00

identify the main

CAN_ID

Byte[1]=0xC4

CAN_ID

Response frame:
data field

29 位 ID

8Byte data field

Size

Bit28~bit24

bit23~8

bit7~0

Byte0~Byte7

description

0x2

Bit8~Bit15: CAN ID of the

target

Byte0=0x00

current motor

motor

Byte1=0xC4

CAN_ID

Byte2=0x56

bit21~16: fault

information (0 none 1 has)
bit21: uncalibrated

Byte3~6:Motor

bit20: Uncalibrated

version number

bit20: Gridlock overload fault

Order from high

bit19: magnetic coding fault

to low

bit18:overtemperature
bit17: Three-phase overcurrent
fault
bit16: undervoltage fault
bit22~23: Mode status
0: Reset mode [reset]
1: Cali mode [calibration]

50

RobStride Motor User Manual

2: Motor mode [Run]

4.1.15.

Read and write a single parameter list

index

Description

Type

R/W Read and

Number of

write

bytes

permission

0: operation mode
1: position mode
(PP)
0X7005

run_mode

2: Velocity mode
3: Operation mode

uint8

1

float

4

float

4

float

4

W/R

Current mode
5: Position mode
(CSP)
0X7006

iq_ref

Current mode Iq
command
Rotational Velocity

0X700A

spd_ref

mode Rotational
speed command

0X700B

limit_torque

torque limit

-11 to 11A
-50 to
50rad/s
0 to 5.5Nm

W/R

W/R
W/R

The default
0X7010

cur_kp

Kp

float

4

value is

W/R

0.17
The default
0X7011

cur_ki

Ki

float

4

value is

W/R

0.012
0 to 1.0,
0X7014

cur_filt_gain

filt_gain

float

4

The default

W/R

value is 0.1
0X7016

loc_ref

0X7017

limit_spd

Position Mode
Angle instruction
Location mode
(CSP) speed limit

float

4

rad

float

4

float

4

0 to 11A

W/R

float

4

rad

R

-11 to 11A

R

0 to
50rad/s

W/R
W/R

Velocity position
0X7018

limit_cur

mode Current
limitation
Mechanical Angle

0x7019

mechPos

0x701A

iqf

iq Filter

float

4

0x701B

mechVel

Speed of the load

float

4

of the loading coil

51

-50 to
50rad/s

R

RobStride Motor User Manual

index

Description

Type

VBUS

Bus voltage

float

4

0x701E

loc_kp kp

at

float

4

0x701F

spd_kp

float

4

speed kp

write

bytes

0x701C

Indicates the

R/W Read and

Number of

permission
V
The default
value is 40
The default
value is 6

R
W/R
W/R

The default
0x7020

spd_ki

ki

float

4

value is

W/R

0.02
0x7021

0x7022

0x7024

0x7025

spd_filt_gain

acc_rad

vel_max

acc_set

Speed filter value

float

4

The default
value is 0.1

W

The default

velocity mode

float

acceleration

4

value is

W

20rad/s^2
The default

Location mode

float

(PP) speed

4

value is

W

10rad/s
The default

Location mode

float

(PP) acceleration

4

value is

W

10rad/s^2

Indicates the
report time. 1
0x7026

EPScan_time

indicates 10ms.

uint16

2

uint32

4

uint8

1

float

4

Plus 1 increments

The default
value is 1

W

by 5ms
can The timeout
0x7028

canTimeout

threshold, 20000 is
1s

The default
value is 0

W

Indicates the zero
0x7029

zero_sta

flag bit, 0 means
0-2π and 1 means

The default
is 0

W

-π-π
0x702B

add_offset

4.1.16.

Zero offset

Read example:

Take reading loc_kp as an example:
Read instruction is

52

The default
is 0

W/R

RobStride Motor User Manual

Size
Description

Bit28~bit24

bit23~8

bit7~0

Byte0~Byte7

0x11

0x00FD

0x7F

1E 70 00 00 00 00 00 00

Type 17

Host id

Target motor

Byte0~1: index,

0xFD

CAN_ID 7F

corresponding to loc_kp

The feedback instruction is
Size

Bit28~bit24

Description

bit23~8

bit7~0

Byte0~Byte7

0x11

0x007F

0xFD

1E 70 00 00 00 00 F0 41

Type 17

bit15~8:

Host

Byte0~1: index, corresponding to

Target

id

loc_kp Byte4~7:loc_kp value 30, high

motor

0xFD

right byte, (32-bit single precision)

CAN_ID 7F

hexadecimal IEEE-754 standard
floating point number

4.2.

Motor Function Description

(If the following features are unavailable, please upgrade to the latest version
via the official Git repository.)

4.2.1. Active Reporting
•

Disabled by default. Enable via Type 24.

•

Report type: Type 2 (default interval: 10ms). Adjust interval by modifying

EPScan_time via Type 18.

4.2.2. Zero-Point Flag (zero_sta)
•

Modify via:
￮

Host computer (上位机)

￮

Type 18 (requires saving via Type 22 for communication)

•

Default flag: 0 → Power-on position range: 0–2π.

•

If set to 1: Power-on position range: π–π.

53

RobStride Motor User Manual

4.2.3. Type 2 Update
•

Updated to periodic looping within -4π–4π (enables cycle counting).

•

Note: Position interface parameters must be adjusted:
￮

P_MIN: 12.57f

￮

P_MAX: 12.57f

4.2.4. Protocol Switching (Requires CAN adapter)
•

Methods:
￮

Modify protocol_1 via host computer.

￮

Send Type 25 command.

•

Reboot required after switching.

•

Post-switch CAN commands:
￮

CANopen: Send extended frame (protocol switch frame).

￮

MIT Protocol: Send standard frame (Command 8).

4.2.5. Post-Power-Off Anti-Backdrive Protection
•

Default: Motor imposes damping if rotated rapidly while powered off

(prevents surge).
•

Disable: Set damper = 1.

54

RobStride Motor User Manual

4.2.6. Zero Calibration Rules
•

Supported modes: CSP and Motion Control.

•

PP Mode: Zero calibration is blocked.

•

Old vs. New Versions:
￮

Old: Zero calibration causes large deviation → motor immediately

moves to target.
￮

New (CSP/Motion Control): Target updates to 0 instantly → motor

remains stationary.

4.2.7. Position Offset (add_offset)
•

Example: If offset = 1, the current zero shifts to (current position + 1

rad).
•

Use case: Bypass mechanical limits (e.g., set zero at 1 rad → power-on

treats 1 rad as new zero).

4.2.8. CANopen ID
•

Old version: Fixed to 1.

•

New version: Matches the private protocol CAN ID.

4.2.9. Notes for Implementation
•

Always save settings (e.g., Type 22 for zero_sta).

•

Verify CAN adapter compatibility for protocol switching.

•

For zero offsets, ensure mechanical safety limits are respected.

55

RobStride Motor User Manual

4.3.

Control mode instructions

4.3.1. Operation control mode

The motor is in operation control mode by default after power-on.
Send motor Enable Run frame (communication type 3) --> Send operation
mode motor control command (communication type 1) --> Receive motor
feedback frame (communication type 2)
Operation control mode description: The control logic of the operation and
control mode is t_ref=Kd * (v_vset-v_actual)+Kp * (p_set-p_actual)+t_ff. Tref is
converted to the expected iq current through an internal formula and output
through the current loop Simple control demonstration: Set t_ff to 0, v_vset to
1, Kd to 1, p_set to 0, Kp to 0. If there is no external load on the motor, it will
run at a speed of 1rad/s. If there is an external load, kd needs to be increased
to resist the external load Set t_ff to 0, v_vset to 0, Kd to 1, p_set to 0, Kp to 0,
the motor is in damping mode. When the motor is externally rotated, a
damping is applied, which increases with the increase of kd. It should be noted
that the motor generates electricity under this condition and requires power
supply to prevent overvoltage Set t_ff to 0, v_vset to 0, Kd to 1, p_set to 5, Kp
to 1. If there is no external load on the motor, it will run to the target position
of 5. Increasing kp will increase the force required to maintain the target
position, and kd is damping. Without kd, the motor will sway to the target
position

56

RobStride Motor User Manual

4.3.2. Current mode

Send motor mode parameter write command (communication type 18) Set the
runmode parameter to 3 --> Send motor Enable run frame (communication
type 3) --> Send motor mode parameter write command (communication
type 18) set the iq_ref parameter to the default current instruction

4.3.3. Velocity mode

Send motor mode parameter write command (communication type 18) Set the
runmode parameter to 2 --> Send motor Enable run frame (communication
type 3) --> Send motor mode parameter write command (communication
type 18) set limit_cur parameter as default maximum current instruction -->
Send motor mode parameter write command (communication type 18) Set
acc_rad parameter as default acceleration instruction --> Send motor mode
parameter write command (communication type 18) Set spd_ref parameter as
default speed instruction

57

RobStride Motor User Manual

4.3.4. Location Mode (CSP)

Send motor mode parameter write command (communication type 18) Set the
runmode parameter to 5 --> Send motor Enable run frame (communication
type 3) --> Send motor mode parameter write command (communication
type 18) set limit_spd parameter as default maximum speed instruction -->
Send motor mode parameter write command (communication type 18) Sets
loc_ref parameter as default position instruction

4.3.5. Location Mode (PP)

Send motor mode parameter write command (communication type 18) Set the
runmode parameter to 1 --> Send motor Enable run frame (communication
type 3) --> Send motor mode parameter write command (communication
type 18) set The vel_max parameter is the default maximum speed instruction
--> Send motor mode parameter write command (communication type 18)
Set the acc_set parameter to the default acceleration instruction --> Send
motor mode parameter write command (communication type 18) Set the
loc_ref parameter to the default position instruction
Note: This mode does not support changing the speed and acceleration
during operation. If you want to make an emergency stop, you can change
vel_max to 0 during the process, and it will stop at the current speed and
acceleration plan

58

RobStride Motor User Manual

4.3.6. Stop running
Sending motor stop frame (communication type 4)

4.4.

Program sample

Examples of various mode control motors are provided below (take gd32f303
as an example)
The following are library, function, and macro definitions for the various
instances
C++
#define P_MIN -12.57f

#define P_MAX 12.57f

#define V_MIN -50.0f

#define V_MAX 50.0f

#define KP_MIN 0.0f

#define KP_MAX 500.0f

#define KD_MIN 0.0f

#define KD_MAX 5.0f

#define T_MIN -5.5f

59

RobStride Motor User Manual

#define T_MAX 5.5f

struct exCanIdInfo{

uint32_t id:8;

uint32_t data:16;

uint32_t mode:5;

uint32_t res:3;

};

can_receive_message_struct rxMsg;

can_trasnmit_message_struct txMsg={

.tx_sfid = 0,

.tx_efid = 0xff,

.tx_ft = CAN_FT_DATA,

.tx_ff = CAN_FF_EXTENDED,

.tx_dlen = 8,

};

60

RobStride Motor User Manual

#define txCanIdEx (*((struct exCanIdInfo*)&(txMsg.tx_efid)))

#define rxCanIdEx (*((struct exCanIdInfo*)&(rxMsg.rx_efid))) //将扩展帧 id 解
析为自定义数据结构

int float_to_uint(float x, float x_min, float x_max, int bits){

float span = x_max - x_min;

float offset = x_min;

if(x > x_max) x=x_max;

else if(x < x_min) x= x_min;

return (int) ((x-offset)*((float)((1<<bits)-1))/span);

}

#define can_txd() can_message_transmit(CAN0, &txMsg)

#define can_rxd() can_message_receive(CAN0, CAN_FIFO1, &rxMsg)
The following lists the common types of communication sent:

4.4.1. Motor Enabled Run frame (communication
type 3)
C++
void motor_enable(uint8_t id, uint16_t master_id)
{

61

RobStride Motor User Manual

txCanIdEx.mode = 3;
txCanIdEx.id = id;
txCanIdEx.res = 0;
txCanIdEx.data = master_id;
txMsg.tx_dlen = 8;
txCanIdEx.data = 0;
can_txd();
}

4.4.2. Operation

control

mode

Motor

control

instruction (communication type 1)
C++
void motor_controlmode(uint8_t id, float torque, float MechPosition, float
speed, float kp, float kd)

{

txCanIdEx.mode = 1;

txCanIdEx.id = id;

txCanIdEx.res = 0;

txCanIdEx.data = float_to_uint(torque,T_MIN,T_MAX,16);

txMsg.tx_dlen = 8;

txMsg.tx_data[0]=float_to_uint(MechPosition,P_MIN,P_MAX,16)>>8;

62

RobStride Motor User Manual

txMsg.tx_data[1]=float_to_uint(MechPosition,P_MIN,P_MAX,16);

txMsg.tx_data[2]=float_to_uint(speed,V_MIN,V_MAX,16)>>8;

txMsg.tx_data[3]=float_to_uint(speed,V_MIN,V_MAX,16);

txMsg.tx_data[4]=float_to_uint(kp,KP_MIN,KP_MAX,16)>>8;

txMsg.tx_data[5]=float_to_uint(kp,KP_MIN,KP_MAX,16);

txMsg.tx_data[6]=float_to_uint(kd,KD_MIN,KD_MAX,16)>>8;

txMsg.tx_data[7]=float_to_uint(kd,KD_MIN,KD_MAX,16);

can_txd();

}

4.4.3. Motor stop frame (communication type 4)
Plain Text
void motor_reset(uint8_t id, uint16_t master_id)

{

txCanIdEx.mode = 4;

txCanIdEx.id = id;

txCanIdEx.res = 0;

63

RobStride Motor User Manual

txCanIdEx.data = master_id;

txMsg.tx_dlen = 8;

for(uint8_t i=0;i<8;i++)

{

txMsg.tx_data[i]=0;

}

can_txd();

}

4.4.4. Motor mode parameter write command
(communication type 18, running mode switch)
Plain Text
uint8_t runmode;

uint16_t index;

void motor_modechange(uint8_t id, uint16_t master_id)

{

txCanIdEx.mode = 0x12;

64

RobStride Motor User Manual

txCanIdEx.id = id;

txCanIdEx.res = 0;

txCanIdEx.data = master_id;

txMsg.tx_dlen = 8;

for(uint8_t i=0;i<8;i++)

{

txMsg.tx_data[i]=0;

}

memcpy(&txMsg.tx_data[0],&index,2);

memcpy(&txMsg.tx_data[4],&runmode, 1);

can_txd();

}

4.4.5. Motor mode parameter write command
(communication type 18, control parameter
write)
Plain Text

65

RobStride Motor User Manual

uint16_t index;

float ref;

void motor_write(uint8_t id, uint16_t master_id)

{

txCanIdEx.mode = 0x12;

txCanIdEx.id = id;

txCanIdEx.res = 0;

txCanIdEx.data = master_id;

txMsg.tx_dlen = 8;

for(uint8_t i=0;i<8;i++)

{

txMsg.tx_data[i]=0;

}

memcpy(&txMsg.tx_data[0],&index,2);

memcpy(&txMsg.tx_data[4],&ref,4);

66

RobStride Motor User Manual

can_txd();

}

67

RobStride Motor User Manual

5.Explanation

of

Canopen

Communication Protocol Types
5.1.

Introduction to CANopen Communication

CANopen is a "higher-level protocol" based on the CAN bus. This means that the
CAN bus (ISO 11898) acts like a container truck, serving as the "transportation
vehicle" for CANopen information. CAN simply implements the transmission of
frames with an 11-bit CAN ID, a Remote Transmission (RTR) bit, and 64 data bits
(related to higher-level protocols). The CAN bus plays the same role in CANopen
as it does in the J1939 protocol. CANopen implements Layer 7 of the OSI model
and is compatible with other data link layer protocols besides CAN.Please
download the necessary EDS files for CANopen from the official website download
center at www.robstride.com.

5.2.

Canopen Protocol Message Classification

Classification

Function

NMT

Manage the network and switch node states. NMT network

Network

Management

management messages are typically sent by the master

Messages

station.
Used for setting device parameters or transmitting critical

SDO Service Data
Object Message

data. Typically, the master station initiates an SDO message,
and the slave station responds. However, a slave station can
also initiate an SDO message, with the master station
responding, for example, in the transmission of critical data.

PDO (Process Data
Object) messages
EMCY

Emergency

Message
SYNC
Synchronization
Message

Transmit process data from various devices, such as
temperature and speed. Both the master and slave stations
send these messages.
Transmits

fault

information

about

the

transmission

equipment. Both the master and slave stations send this
message.
Synchronization data, used to synchronize TPDO data on the
slave station. Generally sent by the master station.

68

RobStride Motor User Manual

Classification

Function

NODE GUARDING

The master station requests the slave station's status; the

Message

master station queries, and the slave station responds.

Heartbeat

A device actively sends a heartbeat to indicate that it is

Message

online. Both the master and slave devices can send
heartbeats.

69

RobStride Motor User Manual

5.3.

State Machine Description

Motor Enable:
When initially powered on, the motor defaults to the SWITCH_ON_DISABLED
state. To transition to OPERATION_ENABLE, modify the Controlword (6040H)
to 6, 7, or 15 (step-by-step transition), or directly set it to 15 for immediate

70

RobStride Motor User Manual

enablement.
Stopping the Motor:
If the motor is in OPERATION_ENABLE state and needs to stop normally,
modify the Controlword (6040H) to 1. The motor will return to the disabled
state (SWITCH_ON_DISABLED).
Emergency Stop (Use with Caution—Risk of Voltage Surge):
During operation, an emergency stop can be triggered by setting the
Controlword (6040H) to 11.
Fault Clearance:
If the motor enters a FAULT state due to protection mechanisms, modifying
the Controlword (6040H) can clear standard errors.
Important Note:
Mode changes for this motor must be performed in the disabled state
(SWITCH_ON_DISABLED). Ensure the desired mode is configured before
enabling OPERATION_ENABLE to avoid unexpected behavior.

5.4.

Status Feedback Parameters

Index

Name

603F

Error_code

6041

Statusword

6061

Modes_of_operation_display

6062

Position_demand_value

6064

Position_actual_value

606B

Velocity_demand_value

606C

Velocity_actual_value

Attribute
Readonly
Readonly
Readonly
Readonly
Readonly
Readonly
Readonly

71

Type

Unit

UINTEGER16

/

UINTEGER16

/

INTEGER8

/

INTEGER32
INTEGER32

Pulses (1 rev = 16,384
pulses)
Pulses (1 rev = 16,384
pulses)

INTEGER32

0.1 rpm

INTEGER32

0.1 rpm

RobStride Motor User Manual

Index

Name

6077

Torque_actual_value

6078

Current_actual_value

6079

DC_link_circuit_voltage

5.5.

Attribute

Type

Read-

Unit
0.1% load ratio (1000

INTEGER16

only
Readonly
Readonly

= 2 N·m)

INTEGER16

mA

INTEGER32

mV

Homing Mode (Zero Position Setting)

Index

Name

Attribute

Type

Unit

6040

Controlword

Read-write

UINTEGER16

/

6060

Modes of operation

Read-write

INTEGER8

/

Homing method:
•

Set Modes of operation to 6 while the motor is in the disabled state

(SWITCH_ON_DISABLED). The motor will then define the current position as
the zero point.
•

To hold the zero position, modify the Controlword to 15, and the motor

will maintain its position at the home location.

5.6.
Index

Position Mode (PP - Profile Position)
Name

6040

Controlword

6060

Modes of operation

6067

Position_window

6068

Position_window_time

6071

Target_torque

607A

Target_position

6081

Profile_velocity

6083

Profile_acceleration

Attribute
Readwrite
Readwrite
Read-

Type
UINTEGER16

/

INTEGER8

/

UINTEGER32

write
Read-

UINTEGER16

write
Read-

INTEGER16

write
Read-

INTEGER32

write
Readwrite
Read-

72

Unit

Pulses (1 rev = 16,384
pulses)
ms
0.1% load ratio (1000 = 2
N·m)
Pulses (1 rev = 16,384
pulses)

UINTEGER32

0.1 rpm

UINTEGER32

0.1 rpm/s

RobStride Motor User Manual

Index

Name

Attribute

Type

Unit

write

Steps to Configure Position Mode (PP):
1.

While the motor is in the disabled state (SWITCH_ON_DISABLED), set

Modes of operation to 1.
Mandatory parameters:

￮
▪

Target_torque (absolute max torque in position mode)

▪

Profile_velocity (absolute speed in position mode)

▪

Profile_acceleration (absolute acceleration in position mode)
Optional parameters:

￮
▪

Position_window (if not set, window check is disabled)

▪

Position_window_time (if not set, window check is disabled)

2.

Set Controlword (6040) to 15 to enable operation.

3.

Set Target_position (absolute position) to move the motor to the desired

position.

5.7.

Position Mode (CSP - Cyclic Synchronous
Position)

Index

Name

6040

Controlword

6060

Modes of operation

6067

Position_window

6068

Position_window_time

6071

Target_torque

Attribute
Readwrite
Readwrite
Read-

Type
UINTEGER16

/

INTEGER8

/

UINTEGER32

write
Read-

UINTEGER16

write
Read-

INTEGER16

write

73

Unit

Pulses (1 rev = 16,384
pulses)
ms
0.1% load ratio (1000 = 2
N·m)

RobStride Motor User Manual

Index

Name

607A

Target_position

6081

Profile_velocity

Attribute

Type

Read-

Unit
Pulses (1 rev = 16,384

INTEGER32

write
Read-

pulses)

UINTEGER32

write

0.1 rpm

Steps to Configure Position Mode (CSP):
1.

While the motor is in the disabled state (SWITCH_ON_DISABLED), set

Modes of operation to 5.
Mandatory parameters:

￮
▪

Target_torque (absolute max torque in position mode)

▪

Profile_velocity (absolute speed in position mode)
Optional parameters:

￮
▪

Position_window (0 = disabled)

▪

Position_window_time (0 = disabled)

2.

Set Controlword (6040) to 15 to enable operation.

3.

Set Target_position (absolute position) to move the motor to the desired

position.

5.8.

Velocity Mode

Index

Name

Attribute

Type

6040

Controlword

Read-write

UINTEGER16

/

Read-write

INTEGER8

/

6060

Modes of
operation

6071

Target_torque

Read-write

INTEGER16

60FF

Target_velocity

Read-write

INTEGER32

Unit

0.1% load ratio (1000 = 2
N·m)
0.1 rpm

Steps to Configure Velocity Mode:
1.

While the motor is in the disabled state (SWITCH_ON_DISABLED), set

Modes of operation to 3.

74

RobStride Motor User Manual

Mandatory parameter:

￮
▪

Target_torque (absolute max torque in velocity mode)

2.

Set Controlword (6040) to 15 to enable operation.

3.

Set Target_velocity to reach the desired speed.

5.9.

Torque Mode

Index

Name

Attribute

Type

Unit

6040

Controlword

Read-write

UINTEGER16

/

Read-write

INTEGER8

/

Read-write

INTEGER16

Modes of

6060

operation

6071

Target_torque

0.1% load ratio (1000 = 2
N·m)

Steps to Configure Torque Mode:
1.

While the motor is in the disabled state (SWITCH_ON_DISABLED), set

Modes of operation to 4.
2.

Set Controlword (6040) to 15 to enable operation.

3.

Set Target_torque to output the desired torque.

5.10. Protocol Switching (Extended Frame): Switch
Motor Protocol (Takes Effect After Power Cycle)
Data Field

29-bit ID

8-Byte Data Area

Size

Bit 28~0

Byte 0~6

Description

0xFFF

01 02 03 04 05 06 F_CMD

F_CMD (Byte 6) defines the motor protocol:
￮

0: Private protocol (default)

￮

1: CANopen protocol

￮

2: MIT protocol
75

RobStride Motor User Manual

Response Frame:
Data Field

11-bit ID

8-Byte Data Area

Size

Bit 10~0

Byte 0~7

Description

Motor ID

64-bit MCU unique identifier

76

RobStride Motor User Manual

6. MIT Communication Protocol Description
The motor communication adopts the CAN 2.0 interface with a default baud
rate of 1 Mbps. The baud rate can be modified by switching to the private
protocol. The standard frame format is as follows:
Data Field

11-bit ID

8-byte Data Area

Size

Bit 10~8

Bit 7~0

Description

Mode type

ID

Byte 0~7

•

Supported Control Modes:

•

MIT Mode: Provides five motion control parameters to the motor.

•

Velocity Mode: Specifies the target speed for the motor.

•

Position Mode: Specifies the target position and speed, allowing the

motor to run to the designated position at the configured speed.

6.1.

Response

Command

1:

Data

Feedback

(Motor Status)
Data Field

11-bit

8-byte Data Area

ID
Size

Bit

Byte 0~7

10~0
Description

Host ID

Byte 0: Motor CAN ID<br>
Byte 1~2: The current angle [0~65535], corresponds to (-12.57
rad ~ 12.57 rad)<br>
Byte 3 (high 8 bits),
Byte 4[7-4] (low 4 bits): The current speed [0~4096], corresponds
to (-50 rad/s ~ 50 rad/s)<br>
Byte 4[3-0] (high 4 bits),
Byte 5 (low 8 bits): The current torque [0~4096], corresponds to (5.5N·m ~ 5.5 N·m)<br>
Byte 6~7: Winding temperature (in degrees)：Temp(Celsius) *10

77

RobStride Motor User Manual

6.2.

Response Command 2: MCU Identification

Data Field

11-bit ID

8-byte Data Area

Size

Bit 10~0

Byte 0~7

Description

Motor ID

64-bit MCU unique identifier

6.3.

Command 1: Enable Motor Operation

Data Field

11-bit ID

8-byte Data Area

Size

Bit 10~0

Byte 0~7

Description

Target motor CAN ID

FF FF FF FF FF FF FF FC

Response: Response Command 1

6.4.

Command 2: Stop Motor Operation

Data Field

11-bit ID

8-byte Data Area

Size

Bit 10~0

Byte 0~7

Description

Target motor CAN ID

FF FF FF FF FF FF FF FD

Response: Response Command 1

6.5.

Command 3: MIT Dynamic Parameters

Data

11-bit

Field

ID

Size

8-byte Data Area

Bit

Byte 0~1: Target angle [0~65535], (-12.57 rad ~ 12.57 rad)

10~0

Byte 2 (high 8 bits),
Byte 3[7-4] (low 4 bits): Target speed [0~4096], (-50 rad/s ~ 50 rad/s)
Byte 3[3-0] (high 4 bits),
Byte 4 (low 8 bits): Kp [0~4096], (0~500)
Byte 5 (high 8 bits),
Byte 6[7-4] (low 4 bits): Kd [0~4096], (0~5)Byte 6[3-0] (high 4 bits),
Byte 7 (low 8 bits): Target torque [0~4096], (-5.5N·m ~ 5.5 N·m)

Response: Response Command 1

78

RobStride Motor User Manual

6.6.

Command 4: Set Zero Position (Non-Position
Mode)

Data Field

11-bit ID

8-byte Data Area

Size

Bit 10~0

Byte 0~7

Description

Target motor CAN ID

FF FF FF FF FF FF FF FE

Response: Response Command 1

6.7.

Command 5: Clear Errors & Read Fault Status

Data

11-bit

Field

ID

Size

8-byte Data Area

Bit

FF FF FF FF FF FF F_CMD FBF_CMD:- 0xFF → Clear current fault- Any

10~0

other value → Returns fault value in

Byte 1 of the

response

Response (Fault Clear): Response Command 1
Fault Status Response:
Data

11-bit

Field

ID

Size

Bit 10~0

8-byte Data Area
Byte 0: Motor CAN ID
Byte 1~4: Fault value (Non-zero: Fault present; 0: Normal)
Bit 14: Stall/I²t overload fault<Bit 7: Encoder not calibrated<br>Bit
3: Overvoltage faultBit 2: Undervoltage faultBit 1: Driver IC faultBit
0: Motor overtemperature fault (Default threshold: 135°C)

Command 6: Set Operation Mode

Response: Response Command 1

6.8.

Command 7: Modify Motor CAN ID

Data Field

11-bit ID

Size

Bit 10~0

8-byte Data Area
FF FF FF FF FF FF F_CMD FAF_CMD: Target motor CAN ID

Response: Response Command 2

79

RobStride Motor User Manual

6.9.

Command

8:

Change

Communication

Protocol (Takes Effect After Power Cycle)
Data
Field
Size

11-bit ID
Bit 10~0

8-byte Data Area
FF FF FF FF FF FF F_CMD FDF_CMD: Protocol type- 0: Private
protocol (default)- 1: CANopen<br>- 2: MIT protocol

Response: Response Command 2

6.10. Command 9: Modify Host CAN ID
Data Field

11-bit ID

Size

Bit 10~0

8-byte Data Area
FF FF FF FF FF FF F_CMD 01F_CMD: Host CAN ID

Response: Response Command 2

6.11. Command

10:

Position

Mode

Control

Command
Data Field

11-bit

8-byte Data Area

ID
Size

Bit 10~8

Bit 7~0

Byte 0~3: Target position (rad, 32-bit float)
Byte 4~7: Target speed (rad/s, 32-bit float)

Description

1

Target motor
CAN ID

Response: Response Command 1

6.12. Command

11:

Velocity

Mode

Control

Command
Data Field

11-bit

8-byte Data Area

ID
Size

Bit

Bit 7~0

10~8

Byte 0~3: Target speed (rad/s, 32-bit float)
Byte 4~7: Current limit in speed/position mode (A,
32-bit float)

Description

2

Target
motor

80

RobStride Motor User Manual

CAN ID

Response: Response Command 1

6.13. Motion Control Mode

The motor defaults to Motion Control Mode upon power-up.
1.

Send the Motor Enable Command (Command 1).

2.

Send the Motion Control Command (Command 3) to activate dynamic

parameter control.
3.

Send the Motor Stop Command (Command 2) to halt operation when

needed.

6.14. Velocity Mode

1.

Configure the motor's operation mode by sending Set Operation Mode

Command (Command 6) with Mode = 2 (Velocity Mode).
2.

Send the Motor Enable Command (Command 1) to activate the motor.

3.

Send the Velocity Mode Control Command (Command 11) to set the

maximum current (absolute value) and target speed.
4.

To stop, send the Motor Stop Command (Command 2).

81

RobStride Motor User Manual

6.15. Position Mode (CSP - Cyclic Synchronous
Position)

1.

Configure the motor's operation mode by sending Set Operation Mode

Command (Command 6) with Mode = 1 (Position Mode).
2.

Send the Motor Enable Command (Command 1) to activate the motor.

3.

Send the Position Mode Control Command (Command 10) to set the

maximum speed (absolute value) and target position.
4.

To stop, send the Motor Stop Command (Command 2).

82

RobStride Motor User Manual

7.Version History
Version Number

Description

Date

1.0

Initial Release

November 25, 2025

83

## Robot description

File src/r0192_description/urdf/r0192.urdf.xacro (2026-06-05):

<?xml version="1.0"?>
<robot xmlns:xacro="http://www.ros.org/wiki/xacro" name="r0192">

    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
    <xacro:arg name="is_ignition" default="true" />

    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
    <xacro:arg name="is_sim" default="true" />

    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
    <xacro:include filename="$(find r0192_description)/urdf/r0192_gazebo.xacro" />

    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
    <xacro:include filename="$(find r0192_description)/urdf/r0192_ros2_control.xacro" />

    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
    <xacro:property name="PI" value="3.14159265359" />
    <xacro:property name="effort" value="30.0" />        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
    <xacro:property name="velocity" value="10.0" />      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
    <xacro:property name="mesh_scale" value="0.001 0.001 0.001" />

    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
    <xacro:macro name="default_inertial" params="mass">
        <inertial>
            <origin xyz="0 0 0" rpy="0 0 0" />
            <mass value="${mass}" />
            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
        </inertial>
    </xacro:macro>


    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
    <link name="world" />

    <link name="base_link">
        <xacro:default_inertial mass="1.0" />
        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
    </link>


    <link name="link_1">
        <xacro:default_inertial mass="1.0" />
        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
    </link>

    <link name="link_2">
        <xacro:default_inertial mass="1.0" />
        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
    </link>

    <link name="link_3">
        <xacro:default_inertial mass="1.0" />
        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
    </link>

    <link name="link_4">
        <xacro:default_inertial mass="1.0" />
        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
    </link>

    <link name="link_5">
        <xacro:default_inertial mass="1.0" />
        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
    </link>

    <link name="link_6">
        <xacro:default_inertial mass="1.0" />
        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
    </link>

     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
    <link name="gripper_base">
        <xacro:default_inertial mass="1.0"/>
        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
    </link>

    <link name="gripper_right">
        <xacro:default_inertial mass="0.01"/>
        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
    </link>

    <link name="gripper_left">
        <xacro:default_inertial mass="0.01"/>
        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
    </link>


    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
    <joint name="virtual_joint" type="fixed">
        <parent link="world" />
        <child link="base_link" />
        <origin xyz="0 0 0" rpy="0 0 0" />
    </joint>

    <joint name="joint_1" type="revolute">
        <parent link="base_link" />
        <child link="link_1" />
        <origin xyz="0 0 0.1751" />
        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
        <axis xyz="0 0 -1" />
        <limit lower="-${PI}" upper="${PI}" effort="${effort}" velocity="${velocity}" />
    </joint>

    <joint name="joint_2" type="revolute">
        <parent link="link_1" />
        <child link="link_2" />
        <origin xyz="0 0.14 0" />
        <axis xyz="0 1 0" />
        <limit lower="-${PI / 2}" upper="${PI / 2}" effort="${effort}" velocity="${velocity}" />
    </joint>

    <joint name="joint_3" type="revolute">
        <parent link="link_2" />
        <child link="link_3" />
        <origin xyz="0 -0.1252 0.185" />
        <axis xyz="0 1 0" />
        <limit lower="-${PI / 4}" upper="${5 * PI / 4}" effort="${effort}" velocity="${velocity}" />
    </joint>

    <joint name="joint_4" type="revolute">
        <parent link="link_3" />
        <child link="link_4" />
        <origin xyz="-0.125 0 0" />
        <axis xyz="1 0 0" />
        <limit lower="-${PI}" upper="${PI}" effort="${effort}" velocity="${velocity}" />
    </joint>

    <joint name="joint_5" type="revolute">
        <parent link="link_4" />
        <child link="link_5" />
        <origin xyz="-0.14 0 0" />
        <axis xyz="0 1 0" />
        <limit lower="-${PI}" upper="${PI}" effort="${effort}" velocity="${velocity}" />
    </joint>

    <joint name="joint_6" type="revolute">
        <parent link="link_5" />
        <child link="link_6" />
        <origin xyz="0 0 0" />
        <axis xyz="1 0 0" />
        <limit lower="-${PI}" upper="${PI}" effort="${effort}" velocity="${velocity}" />
    </joint>

    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
    <joint name ="horizontal_arm_to_claw_support" type="fixed">
        <parent link="link_6"/>
        <child link = "gripper_base"/>
        <origin xyz="-0.119143 0 0.012234"/>
    </joint>

    <joint name ="joint_7" type="prismatic">
        <parent link="gripper_base"/>
        <child link = "gripper_right"/>
        <origin xyz="0 0 0"/>
        <axis xyz="0 1 0"/>
        <limit lower="0.0" upper="0.0025" effort="${effort}" velocity="${velocity}"/>
    </joint>

    <joint name ="joint_8" type="prismatic">
        <parent link="gripper_base"/>
        <child link = "gripper_left"/>
        <origin xyz="0 0 0"/>
        <axis xyz="0 1 0"/>
        <limit lower="-0.0025" upper="0.0" effort="${effort}" velocity="${velocity}"/>
        <mimic joint="joint_7" multiplier="-1"/>
    </joint>

    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
    <link name="tcp"/>
    <joint name="gripper_base_to_tcp" type="fixed">
        <parent link="gripper_base"/>
        <child link="tcp"/>
        <origin xyz="0 0 0" rpy="0 ${PI / 2} 0"/>
    </joint>
</robot>

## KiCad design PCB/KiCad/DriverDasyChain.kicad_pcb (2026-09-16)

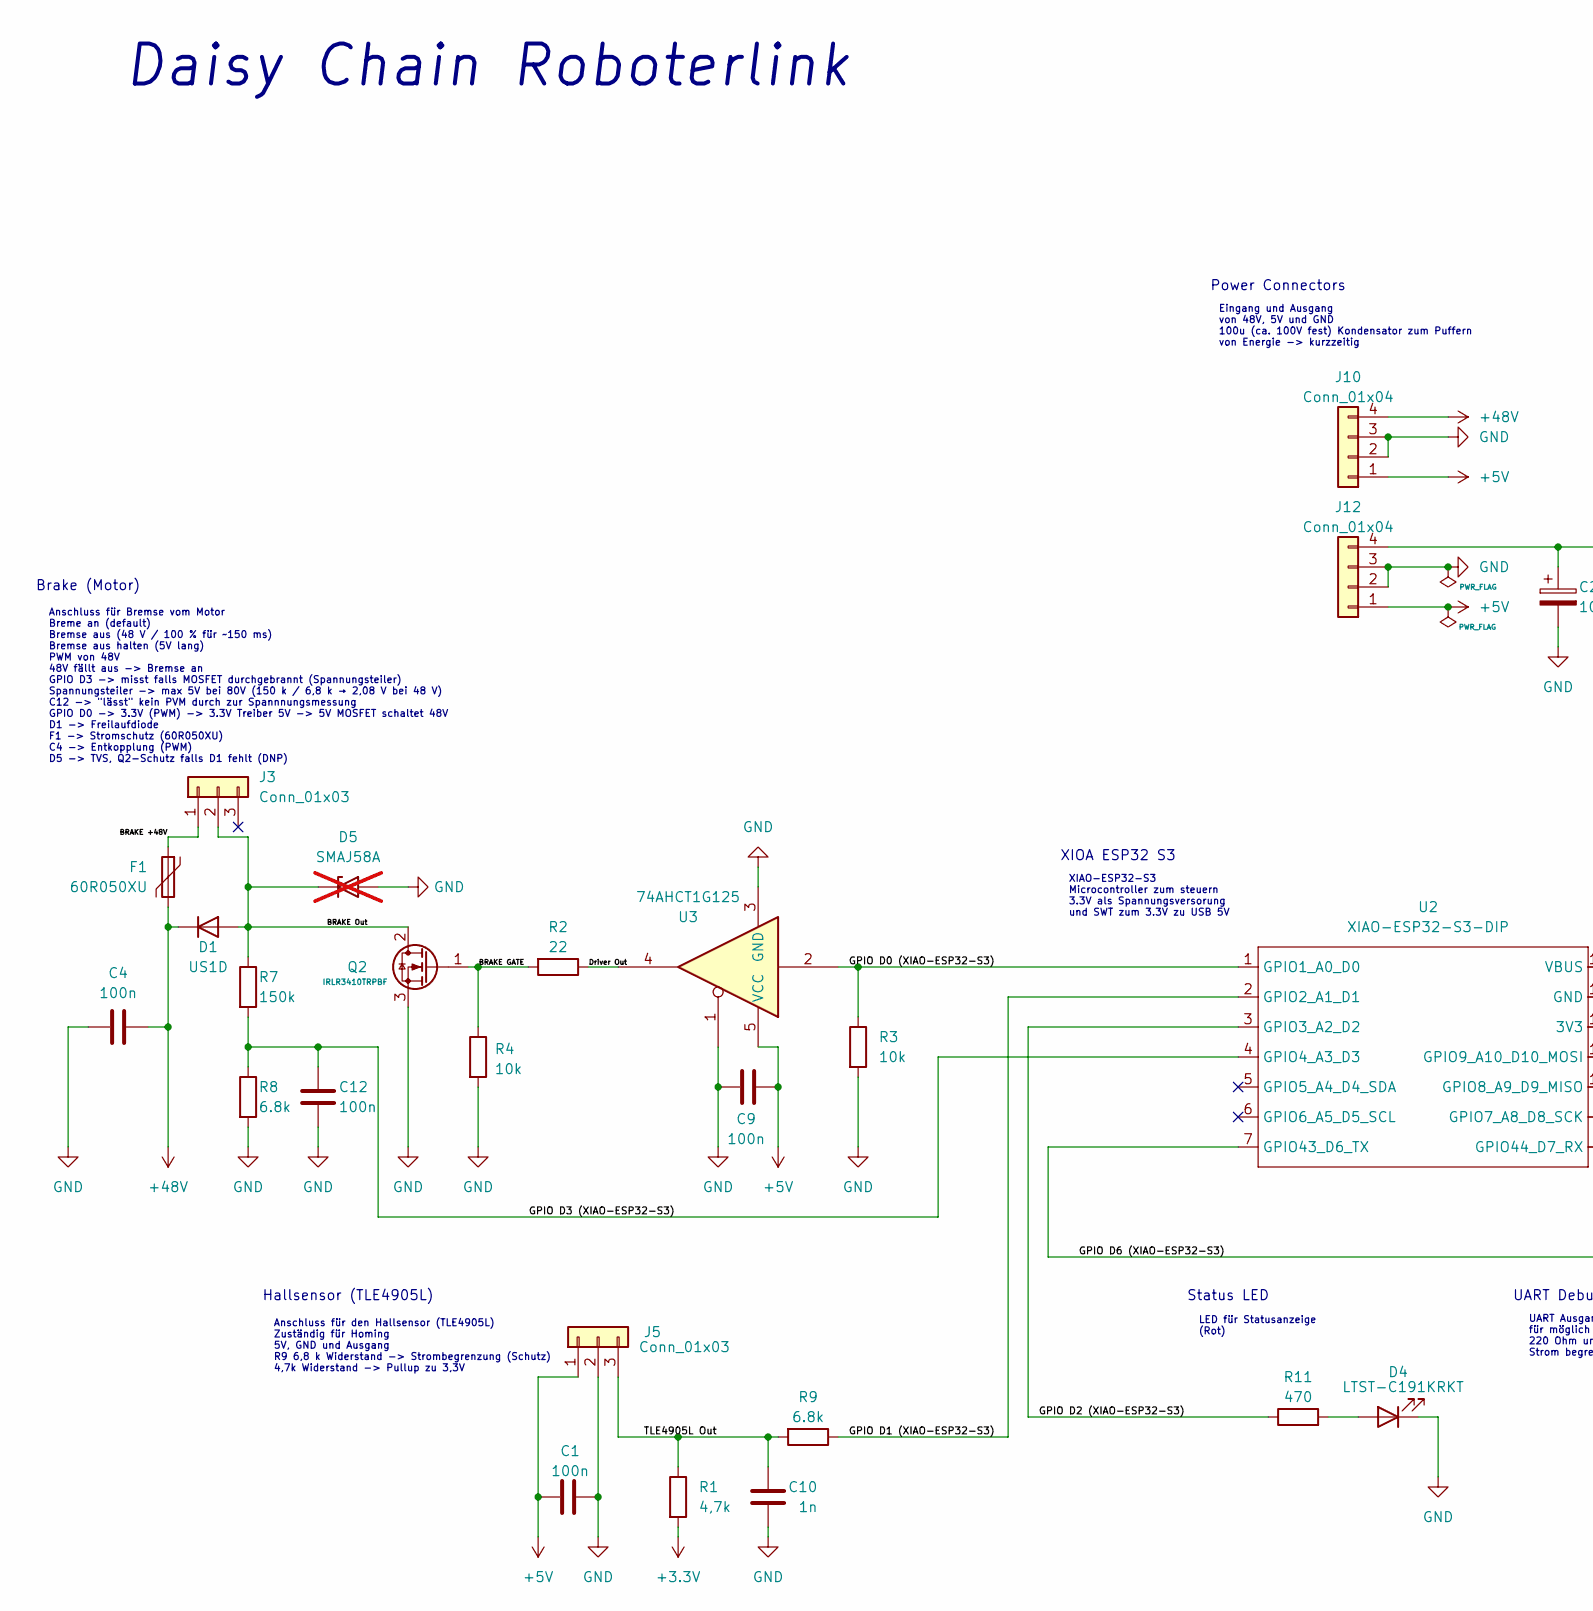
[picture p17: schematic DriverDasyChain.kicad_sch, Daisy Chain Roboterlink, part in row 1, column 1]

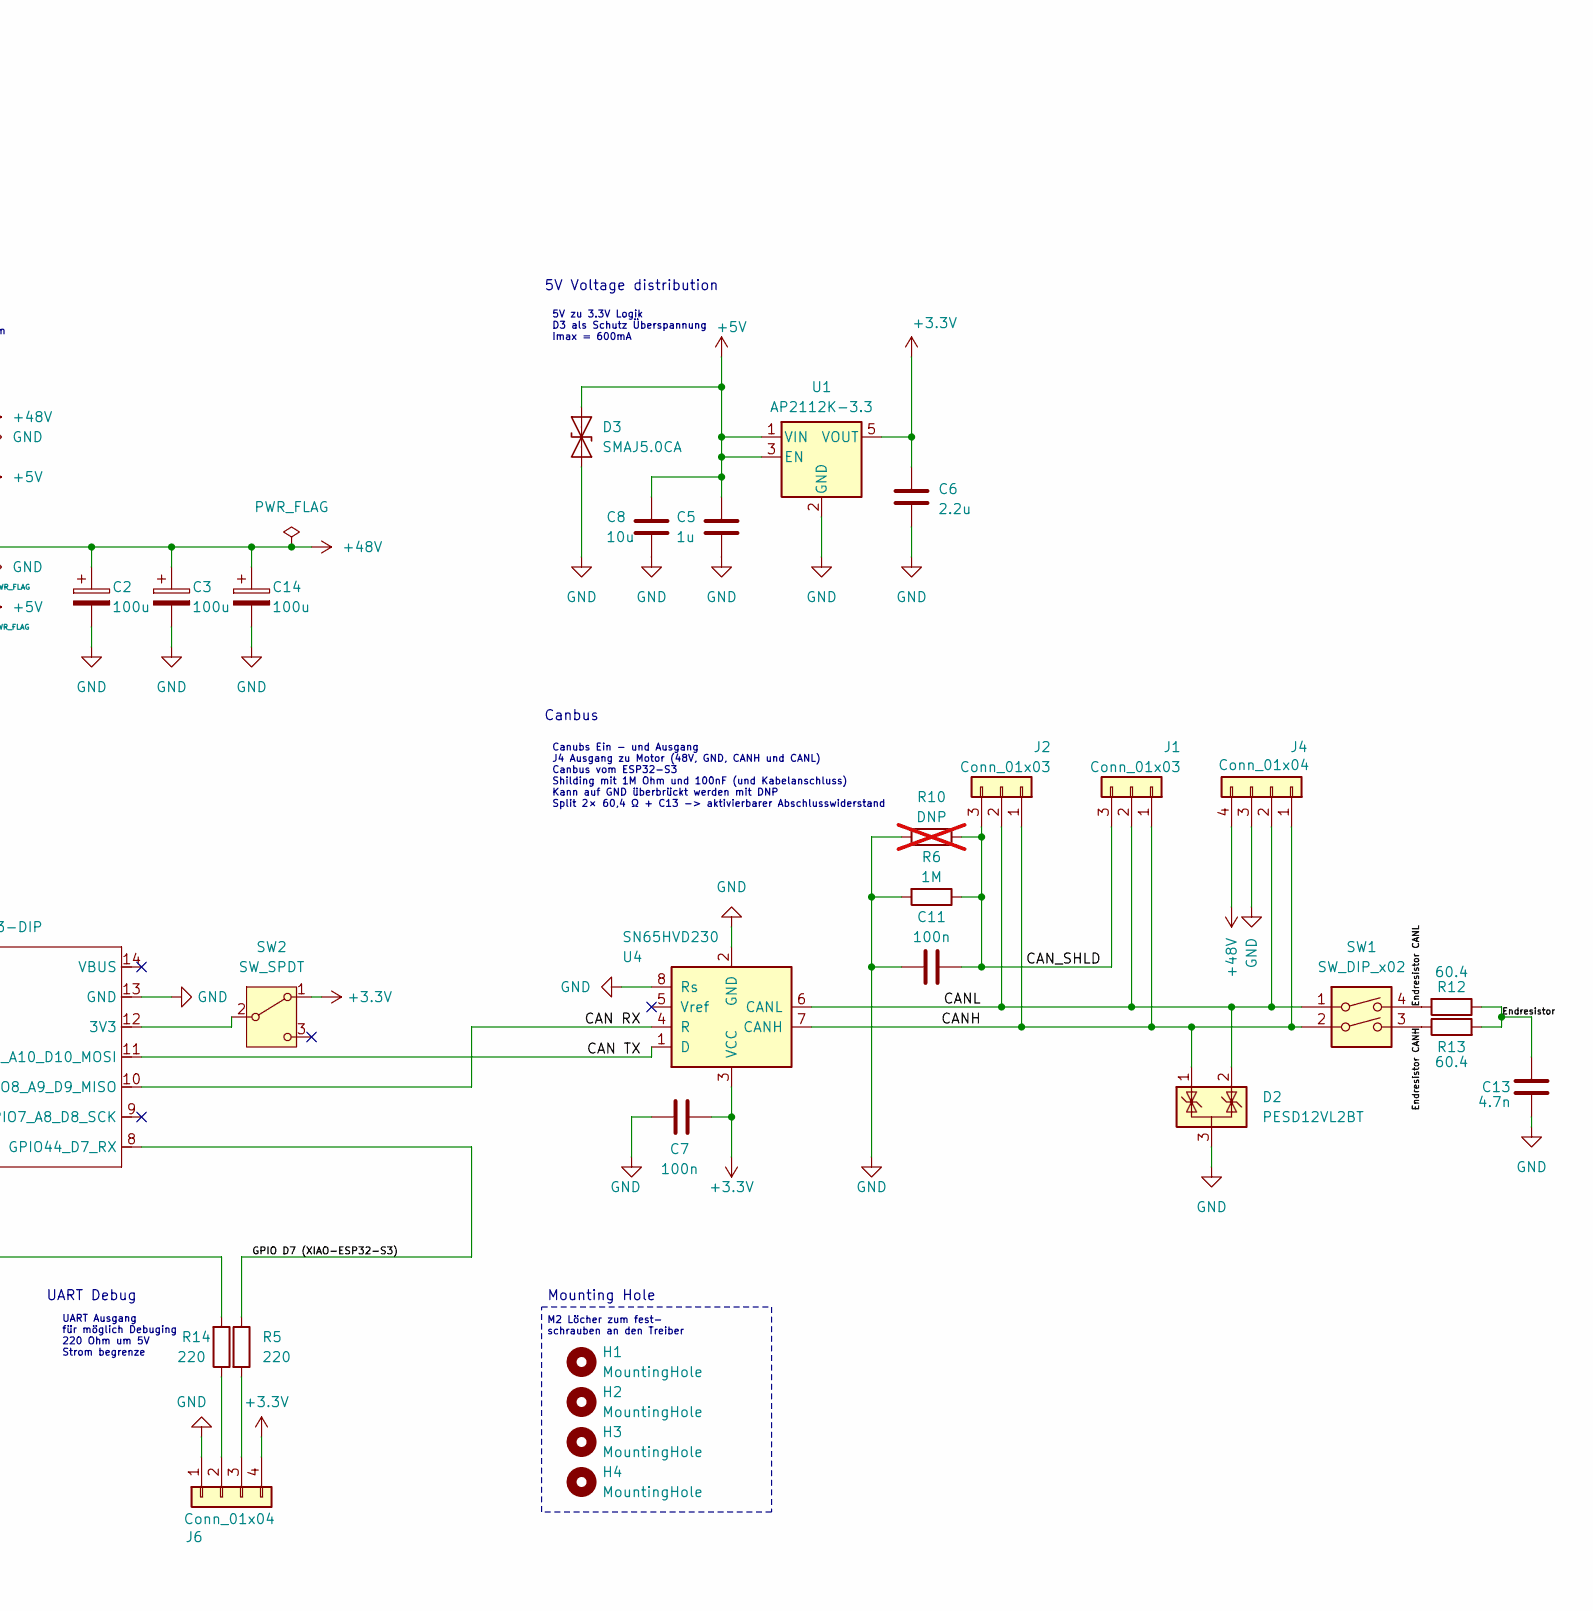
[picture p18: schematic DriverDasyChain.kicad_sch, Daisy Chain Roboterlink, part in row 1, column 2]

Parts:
C1, C7, C9, C11, C12: 100n; C_0603_1608Metric_Pad1.08x0.95mm_HandSolder
C2, C3, C14: 100u; CP_Radial_D10.0mm_P5.00mm
C4: 100n; C_0805_2012Metric_Pad1.18x1.45mm_HandSolder
C5: 1u; C_0603_1608Metric_Pad1.08x0.95mm_HandSolder
C6: 2.2u; C_0603_1608Metric_Pad1.08x0.95mm_HandSolder
C8: 10u; C_0805_2012Metric_Pad1.18x1.45mm_HandSolder
C10: 1n; C_0603_1608Metric_Pad1.08x0.95mm_HandSolder
C13: 4.7n; C_0603_1608Metric_Pad1.08x0.95mm_HandSolder
D1: US1D; D_SMA
D2: PESD12VL2BT; SOT-23
D3: SMAJ5.0CA; D_SMA
D4: LTST-C191KRKT; LED_0603_1608Metric_Pad1.05x0.95mm_HandSolder
D5: SMAJ58A; D_SMA; not fitted
F1: 60R050XU; Fuse_Littelfuse_60R050XU
H1, H2, H3, H4: MountingHole; MountingHole_2.2mm_M2_Pad_TopBottom
J1, J2: Conn_01x03; TerminalBlock_Phoenix_PTSM-0,5-3-2.5-V-THR_1x03_P2.50mm_Ver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
J3, J5: Conn_01x03; JST_PH_B3B-PH-K_1x03_P2.00mm_Vertical
J4, J10, J12: Conn_01x04; TerminalBlock_WAGO_2601-3104_1x04_P3.50mm_Vertical
J6: Conn_01x04; PinHeader_1x04_P2.54mm_Vertical
Q2: IRLR3410TRPBF; TO-252-2
R1: 4,7k; R_0603_1608Metric_Pad0.98x0.95mm_HandSolder
R2: 22; R_0603_1608Metric_Pad0.98x0.95mm_HandSolder
R3, R4: 10k; R_0603_1608Metric_Pad0.98x0.95mm_HandSolder
R5, R14: 220; R_0603_1608Metric_Pad0.98x0.95mm_HandSolder
R6: 1M; R_0603_1608Metric_Pad0.98x0.95mm_HandSolder
R7: 150k; R_0603_1608Metric_Pad0.98x0.95mm_HandSolder
R8, R9: 6.8k; R_0603_1608Metric_Pad0.98x0.95mm_HandSolder
R10: DNP; R_0603_1608Metric_Pad0.98x0.95mm_HandSolder; not fitted
R11: 470; R_0603_1608Metric_Pad0.98x0.95mm_HandSolder
R12, R13: 60.4; R_0603_1608Metric_Pad0.98x0.95mm_HandSolder
SW1: SW_DIP_x02; SW_DIP_SPSTx02_Slide_6.7x6.64mm_W6.73mm_P2.54mm_LowProfile_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
SW2: SW_SPDT; SW_SPDT_PCM12
U1: AP2112K-3.3; SOT-23-5
U2: XIAO-ESP32-S3-DIP
U3: 74AHCT1G125; SOT-23-5
U4: SN65HVD230; SOIC-8_3.9x4.9mm_P1.27mm

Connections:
+3.3V: C6.1, C7.2, J6.4, R1.2, SW2.1 (A), U1.5 (VOUT), U4.3 (VCC)
+5V: C1.1, C5.2, C8.2, C9.2, D3.2 (A2), J5.1, J10.1, J12.1, U1.1 (VIN), U1.3 (EN), U3.5 (VCC)
+48V: C2.1, C3.1, C4.2, C14.1, D1.1 (K), F1.2, J4.4, J10.4, J12.4
/BRAKE +48V: F1.1, J3.1
/BRAKE GATE: Q2.1 (G), R2.2, R4.1
/BRAKE Out: D1.2 (A), D5.1 (A1), J3.2, Q2.2 (D), R7.1
/CAN RX: U2.10 (GPIO8_A9_D9_MISO), U4.4 (R)
/CAN TX: U2.11 (GPIO9_A10_D10_MOSI), U4.1 (D)
/CANH: D2.1 (K), J1.1, J2.1, J4.1, SW1.2, U4.7 (CANH)
/CANL: D2.2 (K), J1.2, J2.2, J4.2, SW1.1, U4.6 (CANL)
/CAN_SHLD: C11.2, J1.3, J2.3, R6.1, R10.2
/Driver Out: R2.1, U3.4
/Endresistor: C13.1, R12.1, R13.2
/Endresistor CANH: R13.1, SW1.3
/Endresistor CANL: R12.2, SW1.4
/GPIO D0 (XIAO-ESP32-S3): R3.1, U2.1 (GPIO1_A0_D0), U3.2
/GPIO D1 (XIAO-ESP32-S3): R9.1, U2.2 (GPIO2_A1_D1)
/GPIO D2 (XIAO-ESP32-S3): R11.1, U2.3 (GPIO3_A2_D2)
/GPIO D3 (XIAO-ESP32-S3): C12.1, R7.2, R8.1, U2.4 (GPIO4_A3_D3)
/GPIO D6 (XIAO-ESP32-S3): R14.2, U2.7 (GPIO43_D6_TX)
/GPIO D7 (XIAO-ESP32-S3): R5.1, U2.8 (GPIO44_D7_RX)
/TLE4905L Out: C10.1, J5.3, R1.1, R9.2
GND: C1.2, C2.2, C3.2, C4.1, C5.1, C6.2, C7.1, C8.1, C9.1, C10.2, C11.1, C12.2, C13.2, C14.2, D2.3 (A), D3.1 (A1), D4.1 (K), D5.2 (A2), J4.3, J5.2, J6.1, J10.2, J10.3, J12.2, J12.3, Q2.3 (S), R3.2, R4.2, R6.2, R8.2, R10.1, U1.2 (GND), U2.13 (GND), U3.1, U3.3 (GND), U4.2 (GND), U4.8 (Rs)
unnamed: D4.2 (A), R11.2
unnamed: J6.2, R14.1
unnamed: J6.3, R5.2
unnamed: SW2.2 (B), U2.12 (3V3)

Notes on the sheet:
XIAO-ESP32-S3 Microcontroller zum steuern 3.3V als Spannungsversorung und SWT zum 3.3V zu USB 5V
Brake (Motor)
5V Voltage distribution
UART Ausgang für möglich Debuging 220 Ohm um 5V Strom begrenze
Canbus
Daisy Chain Roboterlink
Hallsensor (TLE4905L)
Anschluss für Bremse vom Motor Breme an (default) Bremse aus (48 V / 100 % für ~150 ms) Bremse aus halten (5V lang) PWM von 48V 48V fällt aus -> Bremse an GPIO D3 -> misst falls MOSFET durchgebrannt (Spannungsteiler) Spannungsteiler -> max 5V bei 80V (150 k / 6,8 k → 2,08 V bei 48 V) C12 -> "lässt"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
Eingang und Ausgang von 48V, 5V und GND 100u (ca. 100V fest) Kondensator zum Puffern von Energie -> kurzzeitig
Mounting Hole
Status LED
Canubs Ein - und Ausgang J4 Ausgang zu Motor (48V, GND, CANH und CANL) Canbus vom ESP32-S3 Shilding mit 1M Ohm und 100nF (und Kabelanschluss) Kann auf GND überbrückt werden mit DNP Split 2× 60,4 Ω + C13 -> aktivierbarer Abschlusswiderstand
Power Connectors
M2 Löcher zum fest- schrauben an den Treiber
5V zu 3.3V Logik D3 als Schutz Überspannung Imax = 600mA
UART Debug
LED für Statusanzeige (Rot)
XIOA ESP32 S3
Anschluss für den Hallsensor (TLE4905L) Zuständig für Homing 5V, GND und Ausgang R9 6,8 k Widerstand -> Strombegrenzung (Schutz) 4,7k Widerstand -> Pullup zu 3,3V

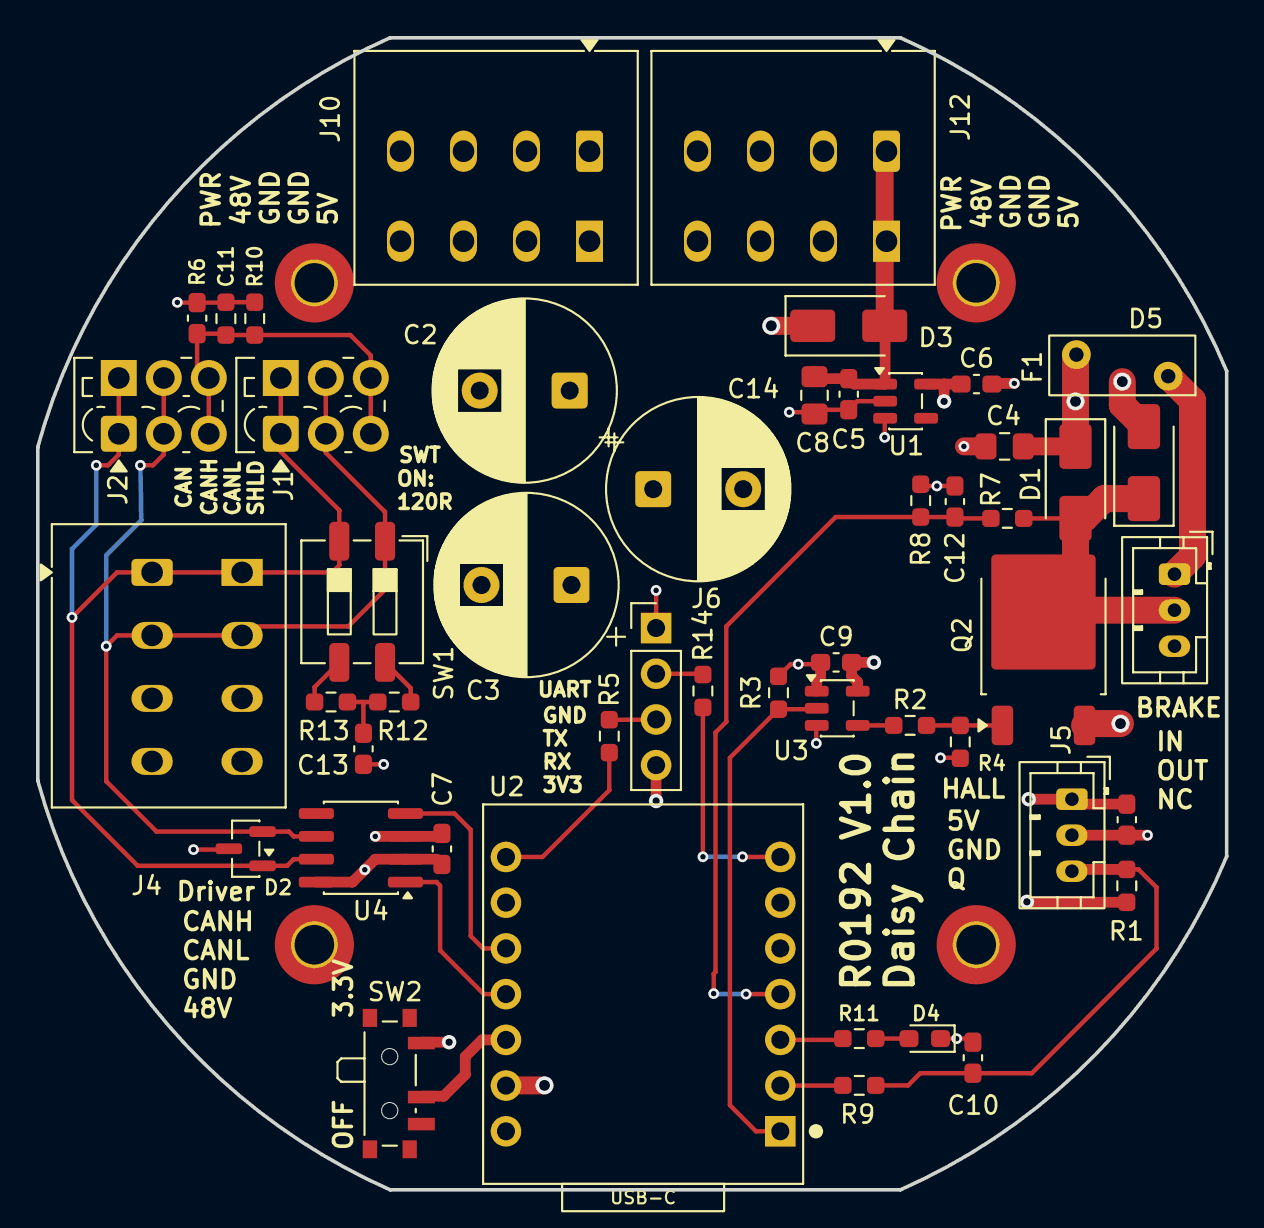
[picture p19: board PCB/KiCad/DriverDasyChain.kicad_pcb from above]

Board: 4 copper layers, 66.1 x 64.0 mm, 53 parts (0 on the bottom side), 27 nets.

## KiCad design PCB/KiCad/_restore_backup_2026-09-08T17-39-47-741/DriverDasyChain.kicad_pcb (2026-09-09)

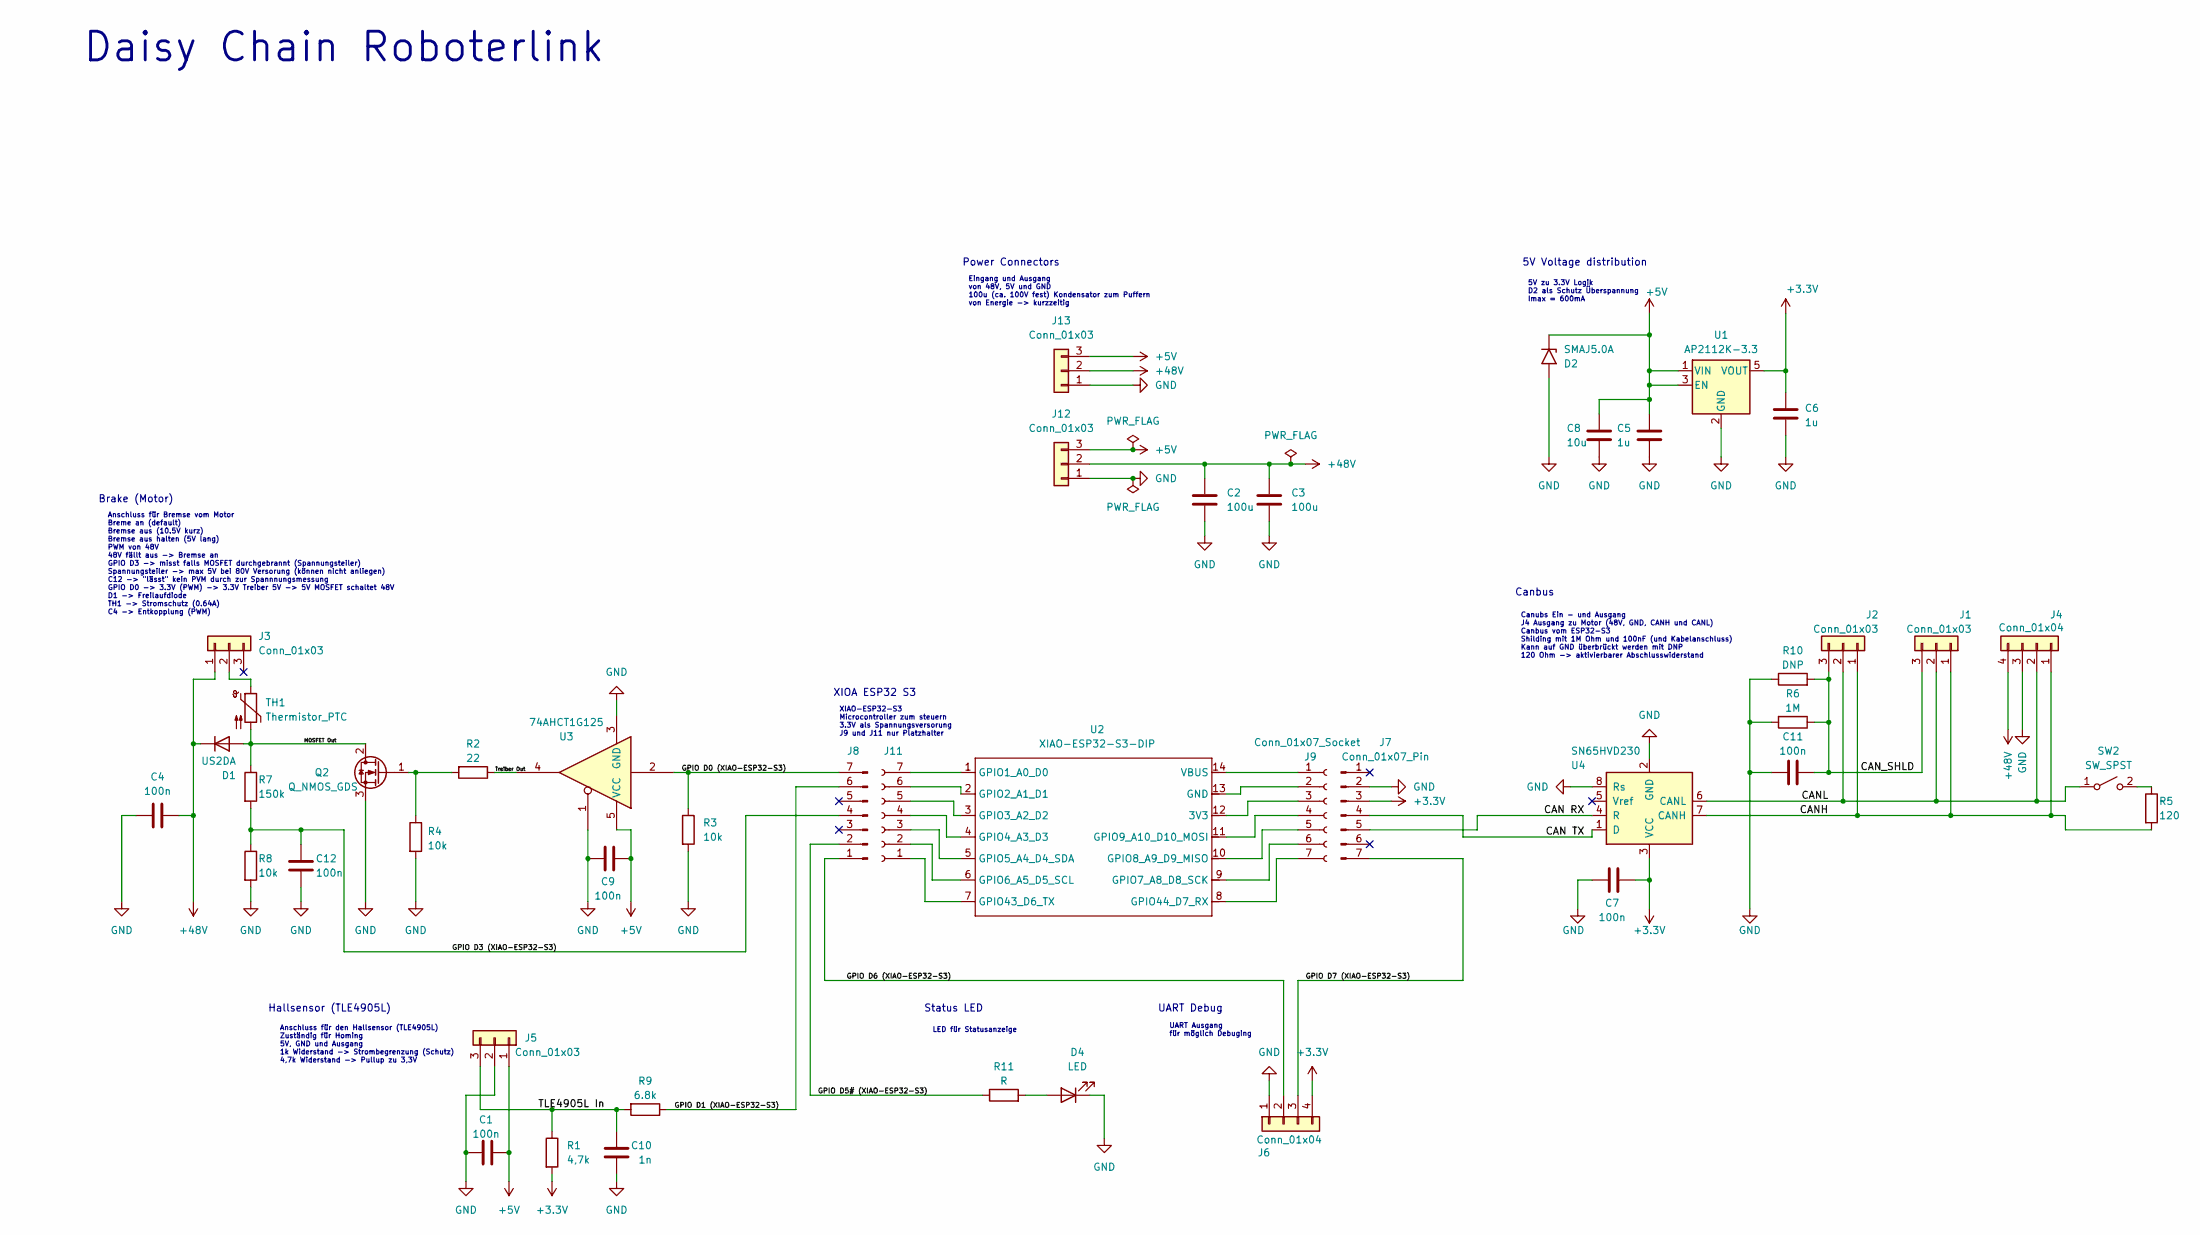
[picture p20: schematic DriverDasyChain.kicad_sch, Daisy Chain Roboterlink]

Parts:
C1, C7, C9, C11, C12: 100n; C_0603_1608Metric_Pad1.08x0.95mm_HandSolder
C2, C3: 100u; CP_Radial_D10.0mm_P5.00mm
C4: 100n; C_0805_2012Metric_Pad1.18x1.45mm_HandSolder
C5, C6: 1u; C_0603_1608Metric_Pad1.08x0.95mm_HandSolder
C8: 10u; C_0805_2012Metric_Pad1.18x1.45mm_HandSolder
C10: 1n; C_0603_1608Metric_Pad1.08x0.95mm_HandSolder
D1: US2DA; D_SMA
D2: SMAJ5.0A; D_SMA
D4: LED; LED_0603_1608Metric_Pad1.05x0.95mm_HandSolder
J1, J2: Conn_01x03; TerminalBlock_Phoenix_PTSM-0,5-3-2.5-V-THR_1x03_P2.50mm_Ver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
J3, J5: Conn_01x03; JST_PH_B3B-PH-K_1x03_P2.00mm_Vertical
J4: Conn_01x04; TerminalBlock_WAGO_2601-3104_1x04_P3.50mm_Vertical
J6: Conn_01x04; PinHeader_1x04_P2.54mm_Vertical
J7, J8: Conn_01x07_Pin; PinHeader_1x07_P2.54mm_Vertical
J9, J11: Conn_01x07_Socket
J12, J13: Conn_01x03; TerminalBlock_WAGO_2601-3104_1x04_P3.50mm_Vertical
Q2: Q_NMOS_GDS; TO-252-2
R1: 4,7k; R_0603_1608Metric_Pad0.98x0.95mm_HandSolder
R2: 22; R_0603_1608Metric_Pad0.98x0.95mm_HandSolder
R3, R4, R8: 10k; R_0603_1608Metric_Pad0.98x0.95mm_HandSolder
R5: 120; R_0603_1608Metric_Pad0.98x0.95mm_HandSolder
R6: 1M; R_0603_1608Metric_Pad0.98x0.95mm_HandSolder
R7: 150k; R_0603_1608Metric_Pad0.98x0.95mm_HandSolder
R9: 6.8k; R_0603_1608Metric_Pad0.98x0.95mm_HandSolder
R10: DNP; R_0603_1608Metric_Pad0.98x0.95mm_HandSolder
R11: R; R_0603_1608Metric_Pad0.98x0.95mm_HandSolder
SW2: SW_SPST; SW_DIP_SPSTx01_Slide_Copal_CHS-01A_W5.08mm_P1.27mm_JPin
TH1: Thermistor_PTC
U1: AP2112K-3.3; SOT-23-5
U2: XIAO-ESP32-S3-DIP
U3: 74AHCT1G125; SOT-23-5
U4: SN65HVD230; SOIC-8_3.9x4.9mm_P1.27mm

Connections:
+3.3V: C6.1, C7.2, J6.4, J7.3, R1.2, U1.5 (VOUT), U4.3 (VCC)
+5V: C1.1, C5.2, C8.2, C9.2, D2.1 (A1), J5.1, J12.3, J13.3, U1.1 (VIN), U1.3 (EN), U3.5 (VCC)
+48V: C2.2, C3.2, C4.2, D1.1 (K), J3.1, J4.4, J12.2, J13.2
/<NO NET>: C10.1, J5.3, Q2.1 (G), R1.1, R2.2, R4.1, R9.2
/CAN RX: J7.5, U4.4 (R)
/CAN TX: J7.4, U4.1 (D)
/CANH: J1.1, J2.1, J4.1, R5.2, U4.7 (CANH)
/CANL: J1.2, J2.2, J4.2, SW2.1 (A), U4.6 (CANL)
/CAN_SHLD: C11.2, J1.3, J2.3, R6.1, R10.2
/GPIO D0 (XIAO-ESP32-S3): J8.7, R3.1, U3.2
/GPIO D1 (XIAO-ESP32-S3): J8.6, R9.1
/GPIO D3 (XIAO-ESP32-S3): C12.1, J8.4, R7.2, R8.1
/GPIO D5# (XIAO-ESP32-S3): J8.2, R11.1
/GPIO D6 (XIAO-ESP32-S3): J6.2, J8.1
/GPIO D7 (XIAO-ESP32-S3): J6.3, J7.7
/MOSFET Out: D1.2 (A), Q2.2 (D), R7.1, TH1.2
/Treiber Out: R2.1, U3.4
GND: C1.2, C2.1, C3.1, C4.1, C5.1, C6.2, C7.1, C8.1, C9.1, C10.2, C11.1, C12.2, D2.2 (A2), D4.1 (K), J4.3, J5.2, J6.1, J7.2, J12.1, J13.1, Q2.3 (S), R3.2, R4.2, R6.2, R8.2, R10.1, U1.2 (GND), U3.1, U3.3 (GND), U4.2 (GND), U4.8 (Rs)
unnamed: D4.2 (A), R11.2
unnamed: J3.2, TH1.1
unnamed: J9.1, U2.14 (VBUS)
unnamed: J9.2, U2.13 (GND)
unnamed: J9.3, U2.12 (3V3)
unnamed: J9.4, U2.11 (GPIO9_A10_D10_MOSI)
unnamed: J9.5, U2.10 (GPIO8_A9_D9_MISO)
unnamed: J9.6, U2.9 (GPIO7_A8_D8_SCK)
unnamed: J9.7, U2.8 (GPIO44_D7_RX)
unnamed: J11.1, U2.7 (GPIO43_D6_TX)
unnamed: J11.2, U2.6 (GPIO6_A5_D5_SCL)
unnamed: J11.3, U2.5 (GPIO5_A4_D4_SDA)
unnamed: J11.4, U2.4 (GPIO4_A3_D3)
unnamed: J11.5, U2.3 (GPIO3_A2_D2)
unnamed: J11.6, U2.2 (GPIO2_A1_D1)
unnamed: J11.7, U2.1 (GPIO1_A0_D0)
unnamed: R5.1, SW2.2 (B)

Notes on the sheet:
XIAO-ESP32-S3 Microcontroller zum steuern 3.3V als Spannungsversorung J9 und J11 nur Platzhalter
Brake (Motor)
5V Voltage distribution
UART Ausgang für möglich Debuging
Canbus
Daisy Chain Roboterlink
Hallsensor (TLE4905L)
Anschluss für Bremse vom Motor Breme an (default) Bremse aus (10.5V kurz) Bremse aus halten (5V lang) PWM von 48V 48V fällt aus -> Bremse an GPIO D3 -> misst falls MOSFET durchgebrannt (Spannungsteiler) Spannungsteiler -> max 5V bei 80V Versorung (können nicht anliegen) C12 -> "lässt" kein PVM durc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
Eingang und Ausgang von 48V, 5V und GND 100u (ca. 100V fest) Kondensator zum Puffern von Energie -> kurzzeitig
Status LED
Canubs Ein - und Ausgang J4 Ausgang zu Motor (48V, GND, CANH und CANL) Canbus vom ESP32-S3 Shilding mit 1M Ohm und 100nF (und Kabelanschluss) Kann auf GND überbrückt werden mit DNP 120 Ohm -> aktivierbarer Abschlusswiderstand
Power Connectors
5V zu 3.3V Logik D2 als Schutz Überspannung Imax = 600mA
UART Debug
LED für Statusanzeige
XIOA ESP32 S3
Anschluss für den Hallsensor (TLE4905L) Zuständig für Homing 5V, GND und Ausgang 1k Widerstand -> Strombegrenzung (Schutz) 4,7k Widerstand -> Pullup zu 3,3V

Board: 4 copper layers, 42 parts (0 on the bottom side), 20 nets, no tracks yet.

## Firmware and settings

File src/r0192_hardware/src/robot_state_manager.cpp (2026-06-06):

// ============================================================================
// robot_state_manager.cpp
//
// Central, authoritative state machine for the R0192 arm (single source of
// truth). Five mutually exclusive states:
//
//   DISABLED  motors off,      arm_controller inactive, servo paused
//   HOLD      motors on,       arm_controller inactive, servo paused
//   JOG       motors on,       arm_controller active,   servo running
//   MOVEIT    motors on,       arm_controller active,   servo paused
//   HOMING    homing sequence running (HomingController manages arm_controller)
//
// JOG / MOVEIT / HOMING are only reachable from HOLD (servos must be on). The
// hard gate is the arm_controller: in HOLD it is deactivated, so move_group's
// FollowJointTrajectory action server is down and MoveIt cannot move the arm;
// the hardware still holds position because write() keeps sending MIT_Control
// with the last setpoint while motors are enabled.
//
// Transitions call the existing services:
//   /robot_enable                       (std_srvs/SetBool)        motor torque
//   /controller_manager/switch_controller (SwitchController)      arm_controller
//   /servo_node/pause_servo             (std_srvs/SetBool)        JOG
//   /homing                             (std_srvs/Trigger)        homing
//
// Emergency stop + reset (front door for clients):
//   /e_stop       (std_srvs/Trigger)  forces DISABLED from ANY state, calls the
//                 hardware /robot_estop (latching driver torque-cut). After an
//                 e-stop the drivers are latched in a fault state.
//   /robot_reset  (std_srvs/Trigger)  calls hardware /robot_clear_faults to
//                 un-latch; required before DISABLED->HOLD works again.
//
// Concurrency: executor-thread callbacks (handleSetState/handleEStop/handleReset)
// are serialized by the single-threaded spin of this node and share client_node_.
// The homing worker runs on a SEPARATE thread, so it uses its own homing_node_ —
// rclcpp forbids spinning the same node from two executors concurrently, which
// would otherwise happen when /e_stop arrives mid-homing.
//
// The node owns the state, publishes it latched on /robot_state, and exposes
// /set_robot_state for clients (RViz JogPanel, future r0192_remote web UI).
// ============================================================================

#include <rclcpp/rclcpp.hpp>

#include <controller_manager_msgs/srv/switch_controller.hpp>
#include <std_srvs/srv/set_bool.hpp>
#include <std_srvs/srv/trigger.hpp>

#include <r0192_interfaces/msg/robot_state.hpp>
#include <r0192_interfaces/srv/set_robot_state.hpp>

#include <chrono>
#include <memory>
#include <mutex>
#include <string>
#include <thread>

using namespace std::chrono_literals;

namespace
{
using RobotState     = r0192_interfaces::msg::RobotState;
using SetRobotState  = r0192_interfaces::srv::SetRobotState;
using SetBool        = std_srvs::srv::SetBool;
using Trigger        = std_srvs::srv::Trigger;
using SwitchController = controller_manager_msgs::srv::SwitchController;

const char * stateName(uint8_t s)
{
  switch (s) {
    case RobotState::DISABLED: return "DISABLED";
    case RobotState::HOLD:     return "HOLD";
    case RobotState::JOG:      return "JOG";
    case RobotState::MOVEIT:   return "MOVEIT";
    case RobotState::HOMING:   return "HOMING";
    default:                   return "UNKNOWN";
  }
}
}  // namespace

class RobotStateManager : public rclcpp::Node
{
public:
  RobotStateManager() : rclcpp::Node("r0192_state_manager")
  {
    managed_controller_ = declare_parameter("managed_controller", std::string("arm_controller"));

    // Latched (transient_local) so late subscribers get the current state.
    auto qos = rclcpp::QoS(1).transient_local();
    state_pub_ = create_publisher<RobotState>("/robot_state", qos);

    // Executor-thread callbacks (set_state / e_stop / reset) share client_node_;
    // they never run concurrently under the single-threaded spin in main().
    client_node_   = std::make_shared<rclcpp::Node>("r0192_state_manager_client");
    enable_client_ = client_node_->create_client<SetBool>("/robot_enable");
    pause_client_  = client_node_->create_client<SetBool>("/servo_node/pause_servo");
    switch_client_ = client_node_->create_client<SwitchController>(
      "/controller_manager/switch_controller");
    estop_client_  = client_node_->create_client<Trigger>("/robot_estop");
    reset_client_  = client_node_->create_client<Trigger>("/robot_clear_faults");

    // The homing worker runs on its own thread, so it gets its own node + clients
    // to avoid spinning client_node_ concurrently with an executor-thread call.
    homing_node_          = std::make_shared<rclcpp::Node>("r0192_state_manager_homing_client");
    homing_client_        = homing_node_->create_client<Trigger>("/homing");
    homing_switch_client_ = homing_node_->create_client<SwitchController>(
      "/controller_manager/switch_controller");

    service_ = create_service<SetRobotState>(
      "/set_robot_state",
      [this](const std::shared_ptr<SetRobotState::Request> req,
             std::shared_ptr<SetRobotState::Response> resp) { handleSetState(req, resp); });

    // Emergency stop: forces DISABLED from ANY state (unlike the normal
    // DISABLED<-HOLD transition). Always available. Calls the hardware
    // /robot_estop (latching driver torque-cut) — the drivers stay trapped in a
    // fault state until /robot_reset clears them.
    estop_service_ = create_service<Trigger>(
      "/e_stop",
      [this](const std::shared_ptr<Trigger::Request> req,
             std::shared_ptr<Trigger::Response> resp) { handleEStop(req, resp); });

    // Reset after e-stop: clears the latched driver faults (hardware
    // /robot_clear_faults) so the motors can be enabled again. Stays in DISABLED.
    reset_service_ = create_service<Trigger>(
      "/robot_reset",
      [this](const std::shared_ptr<Trigger::Request> req,
             std::shared_ptr<Trigger::Response> resp) { handleReset(req, resp); });

    RCLCPP_INFO(get_logger(),
      "Robot state manager ready (/set_robot_state, /robot_state, /e_stop, /robot_reset)");
  }

  ~RobotStateManager() override
  {
    if (homing_thread_.joinable()) homing_thread_.join();
  }

  // Reconcile the real stack with the start state: the controller spawner brings
  // arm_controller up active, but the hardware starts de-energized (DISABLED),
  // so deactivate it once at startup. Tolerant of controller_manager not being
  // up yet. Called from main after the executor is ready.
  void initialize()
  {
    std::string msg;
    if (!callSwitch(switch_client_, client_node_, false, msg)) {
      RCLCPP_WARN(get_logger(),
        "Startup: could not deactivate '%s' (%s) — will reconcile on first transition",
        managed_controller_.c_str(), msg.c_str());
    }
    std::lock_guard<std::mutex> lock(mtx_);
    current_state_ = RobotState::DISABLED;
    publishStateLocked("initialised — torque-free");
  }

private:
  // --------------------------------------------------------------------------
  // Service entry point
  // --------------------------------------------------------------------------
  void handleSetState(const std::shared_ptr<SetRobotState::Request> req,
                      std::shared_ptr<SetRobotState::Response> resp)
  {
    std::lock_guard<std::mutex> lock(mtx_);
    const uint8_t target = req->requested_state;

    if (busy_) {
      reject(resp, "busy — homing or a transition is in progress");
      return;
    }
    if (target > RobotState::HOMING) {
      reject(resp, "unknown requested state");
      return;
    }
    if (target == current_state_) {
      resp->success = true;
      resp->message = std::string("already in ") + stateName(target);
      resp->current_state = current_state_;
      return;
    }

    std::string msg;
    bool ok = false;

    switch (current_state_) {
      case RobotState::DISABLED:
        if (target == RobotState::HOLD) {
          if (estop_latched_) {
            reject(resp, "E-STOP latched — call /robot_reset before enabling");
            return;
          }
          ok = callSetBool(enable_client_, true, "/robot_enable", msg);
        } else {
          msg = "enable servos (HOLD) before JOG/MOVEIT/HOMING";
        }
        break;

      case RobotState::HOLD:
        if (target == RobotState::DISABLED) {
          ok = callSetBool(enable_client_, false, "/robot_enable", msg);
        } else if (target == RobotState::MOVEIT) {
          ok = callSwitch(switch_client_, client_node_, true, msg);
        } else if (target == RobotState::JOG) {
          ok = enterJog(msg);
        } else if (target == RobotState::HOMING) {
          startHoming();              // async; sets state + returns immediately
          resp->success = true;
          resp->message = "homing started";
          resp->current_state = current_state_;
          return;
        } else {
          msg = "invalid transition from HOLD";
        }
        break;

      case RobotState::JOG:
        if (target == RobotState::HOLD) ok = exitJog(msg);
        else msg = "return JOG to HOLD before changing state";
        break;

      case RobotState::MOVEIT:
        if (target == RobotState::HOLD) ok = callSwitch(switch_client_, client_node_, false, msg);
        else msg = "return MOVEIT to HOLD before changing state";
        break;

      default:  // HOMING handled by busy_ above
        msg = "homing in progress";
        break;
    }

    if (ok) {
      current_state_ = target;
      resp->success = true;
      resp->message = std::string("-> ") + stateName(target);
      publishStateLocked(resp->message);
    } else {
      resp->success = false;
      resp->message = msg;
    }
    resp->current_state = current_state_;
  }

  // --------------------------------------------------------------------------
  // Emergency stop — force DISABLED from any state
  // --------------------------------------------------------------------------
  void handleEStop(const std::shared_ptr<Trigger::Request>,
                   std::shared_ptr<Trigger::Response> resp)
  {
    // Cut torque at the driver level FIRST (latching), before touching the
    // mutex — this is the safety-critical action and must not wait on bookkeeping.
    std::string emsg;
    const bool cut = callTrigger(estop_client_, "/robot_estop", emsg);

    std::lock_guard<std::mutex> lock(mtx_);
    estop_latched_ = true;

    if (busy_) {
      // Homing in progress: the homing thread owns axis 1 and drives it directly
      // (bypassing motors_enabled_), so we cannot tear it down here. Flag it to
      // land in DISABLED instead of HOLD; driver torque is already cut.
      // NOTE: v1 does NOT physically interrupt an in-flight homing sweep — that
      // needs a HomingController abort hook (future work).
      estop_ = true;
      resp->success = true;
      resp->message = "E-STOP during homing — torque cut, will land in DISABLED (reset required)";
      RCLCPP_ERROR(get_logger(), "%s", resp->message.c_str());
      return;
    }

    // Full safe teardown from whatever state we were in (best effort).
    std::string msg;
    callSetBool(pause_client_, true, "/servo_node/pause_servo", msg);
    callSwitch(switch_client_, client_node_, false, msg);
    current_state_ = RobotState::DISABLED;
    publishStateLocked("E-STOP — torque cut, DISABLED (reset required)");
    resp->success = cut;
    resp->message = cut ? "E-STOP — drivers latched, call /robot_reset to recover"
                        : ("E-STOP — torque cut best-effort (" + emsg + ")");
    RCLCPP_ERROR(get_logger(), "E-STOP triggered — state forced to DISABLED");
  }

  // --------------------------------------------------------------------------
  // Reset — clear latched driver faults after an e-stop
  // --------------------------------------------------------------------------
  void handleReset(const std::shared_ptr<Trigger::Request>,
                   std::shared_ptr<Trigger::Response> resp)
  {
    std::lock_guard<std::mutex> lock(mtx_);
    if (busy_) {
      resp->success = false;
      resp->message = "busy — cannot reset during homing/transition";
      return;
    }
    std::string msg;
    const bool ok = callTrigger(reset_client_, "/robot_clear_faults", msg);
    if (ok) estop_latched_ = false;
    // Reset leaves us de-energized; ensure we are in DISABLED.
    current_state_ = RobotState::DISABLED;
    publishStateLocked(ok ? "reset — faults cleared, DISABLED" : ("reset failed: " + msg));
    resp->success = ok;
    resp->message = ok ? "drivers reset — ready to enable" : msg;
  }

  // --------------------------------------------------------------------------
  // Composite transitions
  // --------------------------------------------------------------------------
  bool enterJog(std::string & msg)
  {
    if (!callSwitch(switch_client_, client_node_, true, msg)) return false;
    if (!callSetBool(pause_client_, false, "/servo_node/pause_servo", msg)) {
      std::string rb;
      callSwitch(switch_client_, client_node_, false, rb);   // roll back the controller activation
      return false;
    }
    return true;
  }

  bool exitJog(std::string & msg)
  {
    // Pause servo first so it hands the controller back, then deactivate it.
    const bool paused = callSetBool(pause_client_, true, "/servo_node/pause_servo", msg);
    const bool deact  = callSwitch(switch_client_, client_node_, false, msg);
    return paused && deact;
  }

  void startHoming()
  {
    // Safe to join here: reaching this point means busy_ is false, so any prior
    // homing thread has already passed its locked tail section and is exiting.
    if (homing_thread_.joinable()) homing_thread_.join();

    busy_ = true;
    current_state_ = RobotState::HOMING;
    publishStateLocked("homing started");

    homing_thread_ = std::thread([this]() {
      std::string msg;
      const bool ok = callHoming(msg);
      // The HomingController reactivates arm_controller when it finishes; HOLD
      // expects it inactive, so deactivate it again (on the homing node).
      std::string smsg;
      callSwitch(homing_switch_client_, homing_node_, false, smsg);

      std::lock_guard<std::mutex> lock(mtx_);
      busy_ = false;
      if (estop_) {
        estop_ = false;
        current_state_ = RobotState::DISABLED;
        publishStateLocked("homing aborted by E-STOP — DISABLED (reset required)");
      } else {
        current_state_ = RobotState::HOLD;
        publishStateLocked(ok ? ("homing ok: " + msg) : ("homing failed: " + msg));
      }
    });
  }

  // --------------------------------------------------------------------------
  // Service-call helpers. `node` is the node spun while waiting on the future;
  // it MUST be the node the client was created on (see concurrency note above).
  // --------------------------------------------------------------------------
  template <typename FutureT>
  bool waitFuture(const rclcpp::Node::SharedPtr & node, FutureT & future,
                  std::chrono::nanoseconds timeout)
  {
    rclcpp::executors::SingleThreadedExecutor exec;
    exec.add_node(node);
    return exec.spin_until_future_complete(future, timeout) ==
           rclcpp::FutureReturnCode::SUCCESS;
  }

  bool callSetBool(rclcpp::Client<SetBool>::SharedPtr cli, bool data,
                   const char * name, std::string & msg)
  {
    if (!cli->wait_for_service(1s)) { msg = std::string(name) + " unavailable"; return false; }
    auto req = std::make_shared<SetBool::Request>();
    req->data = data;
    auto fut = cli->async_send_request(req);
    if (!waitFuture(client_node_, fut, 5s)) { msg = std::string(name) + " call timed out"; return false; }
    auto resp = fut.get();
    if (!resp->success) { msg = resp->message.empty() ? (std::string(name) + " reported failure")
                                                       : resp->message; return false; }
    return true;
  }

  bool callTrigger(rclcpp::Client<Trigger>::SharedPtr cli, const char * name, std::string & msg)
  {
    if (!cli->wait_for_service(1s)) { msg = std::string(name) + " unavailable"; return false; }
    auto req = std::make_shared<Trigger::Request>();
    auto fut = cli->async_send_request(req);
    if (!waitFuture(client_node_, fut, 5s)) { msg = std::string(name) + " call timed out"; return false; }
    auto resp = fut.get();
    if (!resp->success) { msg = resp->message.empty() ? (std::string(name) + " reported failure")
                                                       : resp->message; return false; }
    return true;
  }

  bool callSwitch(rclcpp::Client<SwitchController>::SharedPtr cli,
                  const rclcpp::Node::SharedPtr & node, bool activate, std::string & msg)
  {
    if (!cli->wait_for_service(1s)) {
      msg = "switch_controller unavailable"; return false;
    }
    auto req = std::make_shared<SwitchController::Request>();
    if (activate) req->activate_controllers   = {managed_controller_};
    else          req->deactivate_controllers = {managed_controller_};
    req->strictness    = SwitchController::Request::BEST_EFFORT;
    req->activate_asap = true;
    auto fut = cli->async_send_request(req);
    if (!waitFuture(node, fut, 5s)) { msg = "switch_controller timed out"; return false; }
    if (!fut.get()->ok) { msg = std::string("could not ") + (activate ? "activate '" : "deactivate '")
                                + managed_controller_ + "'"; return false; }
    return true;
  }

  bool callHoming(std::string & msg)
  {
    if (!homing_client_->wait_for_service(1s)) {
      msg = "/homing unavailable (axis 1 present?)"; return false;
    }
    auto req = std::make_shared<Trigger::Request>();
    auto fut = homing_client_->async_send_request(req);
    if (!waitFuture(homing_node_, fut, 180s)) { msg = "/homing timed out"; return false; }
    auto resp = fut.get();
    msg = resp->message;
    return resp->success;
  }

  // --------------------------------------------------------------------------
  void reject(std::shared_ptr<SetRobotState::Response> & resp, const std::string & why)
  {
    resp->success = false;
    resp->message = why;
    resp->current_state = current_state_;
  }

  void publishStateLocked(const std::string & status)
  {
    RobotState msg;
    msg.state = current_state_;
    msg.status = status;
    state_pub_->publish(msg);
    RCLCPP_INFO(get_logger(), "State -> %s (%s)", stateName(current_state_), status.c_str());
  }

  // --- State ---
  std::mutex mtx_;
  uint8_t current_state_{RobotState::DISABLED};
  bool busy_{false};
  bool estop_{false};          // set by /e_stop while homing; homing thread lands in DISABLED
  bool estop_latched_{false};  // drivers latched after e-stop; needs /robot_reset
  std::string managed_controller_;

  // --- ROS ---
  rclcpp::Publisher<RobotState>::SharedPtr state_pub_;
  rclcpp::Service<SetRobotState>::SharedPtr service_;
  rclcpp::Service<Trigger>::SharedPtr estop_service_;
  rclcpp::Service<Trigger>::SharedPtr reset_service_;

  rclcpp::Node::SharedPtr client_node_;
  rclcpp::Client<SetBool>::SharedPtr enable_client_;
  rclcpp::Client<SetBool>::SharedPtr pause_client_;
  rclcpp::Client<SwitchController>::SharedPtr switch_client_;
  rclcpp::Client<Trigger>::SharedPtr estop_client_;
  rclcpp::Client<Trigger>::SharedPtr reset_client_;

  rclcpp::Node::SharedPtr homing_node_;
  rclcpp::Client<Trigger>::SharedPtr homing_client_;
  rclcpp::Client<SwitchController>::SharedPtr homing_switch_client_;

  std::thread homing_thread_;
};

int main(int argc, char ** argv)
{
  rclcpp::init(argc, argv);
  auto node = std::make_shared<RobotStateManager>();
  node->initialize();
  rclcpp::spin(node);
  rclcpp::shutdown();
  return 0;
}

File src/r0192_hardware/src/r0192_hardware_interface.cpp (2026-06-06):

#include "r0192_hardware/r0192_hardware_interface.hpp"
#include "hardware_interface/types/hardware_interface_type_values.hpp"
#include "rclcpp/rclcpp.hpp"
#include <chrono>
#include <cmath>
#include <cstdio>
#include <vector>

namespace r0192_hardware
{

hardware_interface::CallbackReturn R0192SystemHardware::on_init(const hardware_interface::HardwareInfo & info)
{
  if (hardware_interface::SystemInterface::on_init(info) != hardware_interface::CallbackReturn::SUCCESS) {
    return hardware_interface::CallbackReturn::ERROR;
  }

  hw_positions_.resize(info_.joints.size(), 0.0);
  hw_velocities_.resize(info_.joints.size(), 0.0);
  hw_efforts_.resize(info_.joints.size(), 0.0);

  hw_cmd_positions_.resize(info_.joints.size(), 0.0);
  hw_cmd_velocities_.resize(info_.joints.size(), 0.0);
  hw_cmd_efforts_.resize(info_.joints.size(), 0.0);
  hw_cmd_kp_.resize(info_.joints.size(), 0.0);
  hw_cmd_kd_.resize(info_.joints.size(), 0.0);

  for (size_t i = 0; i < info_.joints.size(); i++) {
    joint_index_[info_.joints[i].name] = i;
    const auto & params = info_.joints[i].parameters;
    if (params.count("kp")) hw_cmd_kp_[i] = std::stod(params.at("kp"));
    if (params.count("kd")) hw_cmd_kd_[i] = std::stod(params.at("kd"));
  }

  return hardware_interface::CallbackReturn::SUCCESS;
}

hardware_interface::CallbackReturn R0192SystemHardware::on_configure(const rclcpp_lifecycle::State & /*previous_state*/)
{
  auto logger = rclcpp::get_logger("R0192Hardware");

  can_comm_ = std::make_shared<CanCommunication>("can0");
  can_available_ = can_comm_->init();

  if (!can_available_) {
    RCLCPP_WARN(logger,
      "CAN socket 'can0' not available — running in virtual (passthrough) mode. "
      "To enable real motors run: sudo ip link set can0 up type can bitrate 500000");
  } else {
    axis1_ = std::make_shared<GDS68Driver>(0x01, can_comm_, logger);
    axis4_ = std::make_shared<RS05Driver>(0x04, can_comm_, logger);

    RCLCPP_INFO(logger, "Probing physical axes (200 ms timeout each)...");
    axis1_present_ = axis1_->probePresent(200);
    axis4_present_ = axis4_->probePresent(200);

    if (!axis1_present_ && !axis4_present_) {
      RCLCPP_WARN(logger, "No physical axes detected — running in full virtual mode");
    } else {
      if (!axis1_present_) RCLCPP_WARN(logger, "Axis 1 (GDS68) not detected — virtual passthrough");
      if (!axis4_present_) RCLCPP_WARN(logger, "Axis 4 (RS05) not detected — virtual passthrough");
    }
    RCLCPP_INFO(logger, "R0192 hardware configured (CAN 'can0' open, axis1=%s axis4=%s)",
      axis1_present_ ? "real" : "virtual", axis4_present_ ? "real" : "virtual");
  }

  return hardware_interface::CallbackReturn::SUCCESS;
}


hardware_interface::CallbackReturn R0192SystemHardware::on_activate(const rclcpp_lifecycle::State & /*previous_state*/)
{
  auto logger = rclcpp::get_logger("R0192Hardware");
  motors_enabled_ = true;  // reset in case a previous cycle left motors disabled
  estop_latched_ = false;  // fresh activation clears any prior e-stop latch

  if (can_available_) {
    rx_thread_running_ = true;
    rx_thread_ = std::thread(&R0192SystemHardware::canRxThread, this);

    // --- Enable motors and request encoder feedback ---
    // (Done before the safety check below so the raw encoder readings are valid;
    //  actual zeroing happens only after the limit check passes.)
    if (axis1_present_) {
      axis1_->Set_Axis_State(8);
      // Position Control (3) + Passthrough (1) to prevent drift.
      axis1_->Set_Controller_Mode(3, 1);
      axis1_->Get_Encoder_Estimates();
    }
    if (axis4_present_) {
      axis4_->Motor_Enabled_To_Run();
      // Enable active reporting (Type 24, F_CMD=01 → 10 ms = 100 Hz) so the RS05
      // streams its Type-2 feedback frame continuously, independent of
      // MIT_Control / motor enable state. Without this the RS05 only replies
      // with feedback while we actively command it, so a disabled motor would
      // report nothing — same goal as the GDS68 0x009 periodic frame. Set purely
      // over CAN (no tool needed); not persisted to flash, so it is re-sent on
      // every activation. The Type-2 frame is parsed identically whether it
      // arrives as a MIT response or an active report, so no read-path change is
      // needed.
      axis4_->Actively_Reports_Frame(1.0f);
    }
    // Let the first feedback frame stream back before reading the encoders.
    if (axis1_present_ || axis4_present_) {
      std::this_thread::sleep_for(std::chrono::milliseconds(100));
    }
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

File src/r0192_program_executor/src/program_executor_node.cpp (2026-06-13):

// ============================================================================
// program_executor_node.cpp
//
// Backend of the R0192 program system (engineering in VS Code, operations in
// the RViz ProgramPanel). Executes YAML programs step by step and is the only
// component with program business logic.
//
//   /execute_program   (r0192_interfaces/action/ExecuteProgram)
//     Goal carries a file path (absolute, or relative to the programs_dir
//     parameter). Points are loaded from points_file. One goal at a time.
//
// State handling: exclusively via /set_robot_state (robot_state_manager).
//   - Before the first step the executor requests MOVEIT (rejected by the
//     manager unless the arm is in HOLD -> the goal aborts with that reason).
//   - On finish / failure / cancel it requests HOLD again, but only if the
//     state is still MOVEIT — after an /e_stop the state is DISABLED and a
//     HOLD request would mean "enable motors", which is not ours to decide.
//
// Execution model:
//   Two step vocabularies and two run modes.
//   - "Stop at each point" (goal.blend == false, default): each move step is
//     planned + executed on its own.
//       move_j: OMPL plan+execute (joint or pose).      ptp: Pilz PTP.
//       move_l: KDL computeCartesianPath (Cartesian).   lin: Pilz LIN.
//       circ:   rejected (needs blend mode).            wait: cancel-responsive sleep.
//     velocity/acceleration (vel/acc) are MoveIt scaling factors in (0, 1].
//   - "Blend through" (goal.blend == true): consecutive move steps are batched
//     into one Pilz MotionSequenceRequest (planner per step, blend_radius=c_dis,
//     last item forced to 0) and sent to the /sequence_move_group action. circ
//     is supported here (via point = interim). wait steps split a sequence.
//
// Cancel: handle_cancel calls MoveGroupInterface::stop() (sequential) and
// cancels the active /sequence_move_group goal (blend). The worker then reports
// CANCELED and returns the state to HOLD.
//
// Threading: the action callbacks run on the main spin; each accepted goal
// runs in its own worker thread (goals are serialized via busy_). The
// /set_robot_state futures complete because the main spin keeps serving this
// node while the worker waits. MoveGroupInterface spins its own internal
// callback thread, so its blocking calls are safe here.
// ============================================================================

#include <rclcpp/rclcpp.hpp>
#include <rclcpp_action/rclcpp_action.hpp>

#include <moveit/move_group_interface/move_group_interface.hpp>
#include <moveit/kinematic_constraints/utils.hpp>
#include <moveit/robot_state/conversions.hpp>

#include <moveit_msgs/action/move_group_sequence.hpp>
#include <moveit_msgs/msg/motion_sequence_request.hpp>
#include <moveit_msgs/msg/display_trajectory.hpp>

#include <sensor_msgs/msg/joint_state.hpp>
#include <visualization_msgs/msg/marker_array.hpp>
#include <std_msgs/msg/float32.hpp>
#include <std_srvs/srv/trigger.hpp>
#include <tf2_ros/buffer.h>
#include <tf2_ros/transform_listener.h>

#include <r0192_interfaces/action/execute_program.hpp>
#include <r0192_interfaces/msg/robot_state.hpp>
#include <r0192_interfaces/srv/delete_point.hpp>
#include <r0192_interfaces/srv/list_points.hpp>
#include <r0192_interfaces/srv/set_program_override.hpp>
#include <r0192_interfaces/srv/set_robot_state.hpp>
#include <r0192_interfaces/srv/teach_point.hpp>

#include "r0192_program_executor/program_loader.hpp"

#include <algorithm>
#include <array>
#include <atomic>
#include <chrono>
#include <cstdlib>
#include <filesystem>
#include <map>
#include <memory>
#include <mutex>
#include <string>
#include <thread>

using namespace std::chrono_literals;

namespace r0192_program_executor
{

using ExecuteProgram = r0192_interfaces::action::ExecuteProgram;
using GoalHandle = rclcpp_action::ServerGoalHandle<ExecuteProgram>;
using RobotStateMsg = r0192_interfaces::msg::RobotState;
using SetRobotState = r0192_interfaces::srv::SetRobotState;
using TeachPoint = r0192_interfaces::srv::TeachPoint;
using ListPoints = r0192_interfaces::srv::ListPoints;
using DeletePoint = r0192_interfaces::srv::DeletePoint;
using SetProgramOverride = r0192_interfaces::srv::SetProgramOverride;
using Trigger = std_srvs::srv::Trigger;
using MoveGroupInterface = moveit::planning_interface::MoveGroupInterface;
using MoveGroupSequence = moveit_msgs::action::MoveGroupSequence;

namespace
{
// Arm joints in point order (matches the SRDF group r0192_arm and the
// 'joints:' arrays in points.yaml).
constexpr std::array<const char *, 6> kArmJoints = {
  "joint_1", "joint_2", "joint_3", "joint_4", "joint_5", "joint_6"};

std::string expandUser(std::string path)
{
  if (!path.empty() && path[0] == '~') {
    if (const char * home = std::getenv("HOME")) {
      path = std::string(home) + path.substr(1);
    }
  }
  return path;
}

bool isMoveStep(const std::string & t)
{
  return t == "move_j" || t == "move_l" || t == "ptp" || t == "lin" || t == "circ";
}

// Pilz planner id for a move step. Legacy aliases map onto their KRL twin
// (move_j ~ ptp, move_l ~ lin).
const char * pilzPlannerId(const std::string & t)
{
  if (t == "lin" || t == "move_l") return "LIN";
  if (t == "circ") return "CIRC";
  return "PTP";   // ptp / move_j
}
}  // namespace
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

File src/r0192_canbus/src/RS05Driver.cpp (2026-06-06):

#include "r0192_canbus/RS05Driver.hpp"
#include <cstring>
#include <cmath>
#include <chrono>


RS05Driver::RS05Driver(uint8_t node_id, std::shared_ptr<CanCommunication> comm, rclcpp::Logger logger) 
    : node_id_(node_id), comm_(comm), logger_(logger) {} 

// ------------------ Canbus Protokoll: CAN 2.0 (siehe Doku) ------------------

// ------------------ Canbus Write ------------------

// 4.1.1. Communication type 0: Get device ID
// force_extended=true because comm_type=0x00 makes the ID equal to just node_id_
// (e.g. 4), which is < 0x7FF and would otherwise be sent as a standard 11-bit frame.
bool RS05Driver::Get_Device_ID(){
    uint8_t data[8] = {0x00, 0x00, 0x00, 0x00, 0x00, 0x00, 0x00, 0x00};
    uint32_t ext_id = (0x00 << 24) | node_id_;
    RCLCPP_DEBUG(logger_, "Axis %d: Get device ID", node_id_);
    return comm_->sendFrame(ext_id, 8, data, true);
}

// 4.1.2. Communication Type 1: operation control mode motor control instruction
bool RS05Driver::MIT_Control(float target_pos, float target_vel, float kp, float kd, float torque){
    
    // 1. Werte limitieren und gemäß Abschnitt 4.1.2 in 16-Bit (0-65535) umrechnen
    
    // Position (16 bit): Skaliert von -4π bis 4π (-12.56637f bis 12.56637f)
    float pos_clamp = std::clamp(target_pos, -12.56637f, 12.56637f);
    uint16_t pos_int = static_cast<uint16_t>((pos_clamp + 12.56637f) * 65535.0f / (2.0f * 12.56637f));
    
    // Speed (16 bit): Skaliert von -50 bis 50 rad/s 
    float speed_clamp = std::clamp(target_vel, -50.0f, 50.0f);
    uint16_t vel_int = static_cast<uint16_t>((speed_clamp + 50.0f) * 65535.0f / 100.0f);
    
    // KP (16 bit): Skaliert von 0 bis 500 
    float kp_clamp = std::clamp(kp, 0.0f, 500.0f);
    uint16_t kp_int = static_cast<uint16_t>(kp_clamp * 65535.0f / 500.0f);
    
    // KD (16 bit): Skaliert von 0 bis 5 
    float kd_clamp = std::clamp(kd, 0.0f, 5.0f);
    uint16_t kd_int = static_cast<uint16_t>(kd_clamp * 65535.0f / 5.0f);
    
    // Torque (16 bit): Skaliert von -5.5 bis 5.5 Nm 
    float torque_clamp = std::clamp(torque, -5.5f, 5.5f);
    uint16_t t_int = static_cast<uint16_t>((torque_clamp + 5.5f) * 65535.0f / 11.0f);
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

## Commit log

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2026-05-08 Refactor r0192 project: Remove obsolete files and implement new hardware interface
    - Deleted `can_service_node.cpp` and associated service files as they are no longer needed.
    - Removed `MotorCommand.srv` and related message definitions from `r0192_msgs`.
    - Eliminated `r0192_controller` interface files and related implementations.
    - Removed `angle_conversion` utility and its associated files from `r0192_utils`.
    - Introduced new `R0192SystemHardware` interface in `r0192_hardware` to manage hardware communication and control.
    - Implemented CAN communication and driver management within the new hardware interface.
    - Updated CMakeLists and package.xml files to reflect the removal of unused packag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
    [GDS68Driver.cpp, GDS68Driver.hpp, r0192_hardware_interface.cpp]
2026-05-10 Refactor robotic arm configuration: update controller parameters and add new hardware interface files
    [r0192_controllers.yaml]
2026-05-10 Refactor RS05Driver and GDS68Driver integration, enhance CAN communication handling, and update MoveIt configuration
    - Implemented placeholder return values for unimplemented functions in RS05Driver.
    - Added thread safety for feedback frame processing in RS05Driver.
    - Updated CMakeLists.txt to remove unnecessary dependencies and streamline build process.
    - Increased update rate in r0192_controllers.yaml for improved control responsiveness.
    - Adjusted joint limits in URDF files for gripper joints to ensure correct operation.
    - Enhanced r0192_ros2_control.xacro for better simulation and real robot handling.
    - Created r0192_hardware package with a shared library for hardware interface.
    - Implem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
    [r0192.urdf.xacro, r0192_controllers.yaml, r0192_ros2_control.xacro]
2026-05-12 Enhance GDS68Driver and configuration: add Set_Linear_Count method, enable open loop control, and adjust MoveIt execution timeout margins
    [r0192_controllers.yaml, r0192_ros2_control.xacro]
2026-05-12 feat: switch axis 1 control mode from MIT_Control to internal position control to mitigate drift
    [GDS68Driver.cpp, r0192_hardware_interface.cpp]
2026-05-12 refactor: disable automatic homing sequence, increase controller update rate, and enable closed-loop trajectory control with relaxed tolerances
    [r0192_controllers.yaml]
2026-05-12 chore: update controller update rate to 100Hz, disable encoder estimates, and add RS05 manual documentation
    [r0192_controllers.yaml]
2026-05-12 refactor: replace software-based offset homing with hardware-level zero setting and remove unused diagnostic logging.
    [r0192_hardware_interface.cpp]
2026-05-12 feat: revert joint_1 command to MIT_Control for improved hardware synchronization
    [r0192_hardware_interface.cpp]
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2026-05-30 feat: Arduino homing sequence – edge-approach algorithm, robust protocol & zeroing
    Reworks the axis-1 homing into a reliable, encoder-agnostic sequence.
    Arduino firmware (r0192_homing.ino):
    - Single axis-specific CAN ID for RX+TX; meaning in Data[0]
    (CMD_ARM 0x01 / RSP_DETECTED 0xFF / RSP_ERROR 0xEE)
    - Timeout so the node never hangs when no magnet is seen
    - Debug logging filtered to the node's own CAN ID
    Homing (extracted into HomingController, own node + executor):
    - Two-sided edge approach: edge A -> overshoot -> edge B -> midpoint
    - Ramped position setpoints for sweep and moves (search_kp / move_vel)
    so the motor drives itself slowly instead of stalling or snapping
    - Pre-check "a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
    [r0192.urdf.xacro]
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2026-05-31 feat: add auto-reset functionality for RViz displays after homing
    [operator_panel.cpp]
2026-06-05 Add JogPanel for teach-pendant style jogging and integrate MoveIt Servo
    - Introduced a new JogPanel in r0192_rviz_plugins for controlling the R0192 arm via teach-pendant style jogging.
    - Implemented joint and Cartesian jogging modes with corresponding buttons and a speed slider.
    - Integrated the JogPanel with MoveIt Servo for real-time control, allowing for smooth operation while maintaining safety.
    - Updated launch files to include the new servo_node for handling jogging commands.
    - Modified URDF to add a TCP link for tool frame reference.
    - Enhanced the r0192_hardware_interface to ensure motors remain disabled after activation until explicitly enabled by the operator.
    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
    [r0192.urdf.xacro, servo.yaml]
2026-06-05 Refactor URDF and RViz configurations for real-scale implementation
    - Updated joint limits for joint_7 in CLAUDE.md and URDF to reflect real dimensions (0.0025 m).
    - Adjusted URDF geometry scaling to 1:1 with real measurements, modifying mesh scales and joint origins accordingly.
    - Revised MoveIt configuration to restore default singularity thresholds, now suitable for real-scale links.
    - Enhanced RViz configuration for improved visualization, including adjustments to grid size and view settings.
    - Implemented live readout for joint angles and TCP pose in jog_panel, utilizing TF for real-time updates.
    - Added necessary dependencies for sensor_msgs and tf2 in CMakeLists.txt and package.xml.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
    [r0192.urdf.xacro, servo.yaml]
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2026-06-06 feat: Implement robot state manager and interfaces for R0192 arm
    - Added a new `robot_state_manager` node to manage the state transitions of the R0192 arm.
    - Introduced five states: DISABLED, HOLD, JOG, MOVEIT, and HOMING, with appropriate service calls for transitions.
    - Created custom ROS 2 interfaces in `r0192_interfaces` package, including `RobotState.msg` and `SetRobotState.srv`.
    - Updated `jog_panel` to interact with the new state manager, replacing previous service calls with state transitions.
    - Added emergency stop and reset functionalities to handle faults and state management.
    - Enhanced UI feedback based on the current robot state, ensuring clear communication of status to the us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
    [RS05Driver.cpp, RS05Driver.hpp, jog_panel.cpp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]
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2026-06-11 feat: program executor backend MVP (r0192_program_executor)
    New package with /execute_program action server: YAML loader as the single
    parse/validate point (strict messages, unknown keys rejected), sequential
    move_j (joint+pose targets via MoveGroupInterface, lazy-created) and wait
    steps, cancel via MoveGroupInterface::stop().
    State strictly via /set_robot_state: HOLD->MOVEIT before the first step,
    MOVEIT->HOLD on finish/cancel/failure — only while the state is still MOVEIT
    (untouched after /e_stop). Registered in real_robot.launch.py; demo program +
    point database in programs/.
    Tested virtually: 4-step demo SUCCEEDED + back to HOLD, mid-program cancel ->
    CANCELED + HOLD, goal from DISAB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
    [points.yaml, program_demo.yaml, program_executor_node.cpp]
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2026-06-11 feat(rviz): program run panel (phase 3) — runtime-only ProgramPanel
    New r0192_rviz_plugins::ProgramPanel ('R0192 Program' in moveit.rviz):
    file picker over programs/ (combo + browse, directory persisted in the rviz
    config), read-only YAML view with syntax highlighting, Run/Stop via the
    /execute_program action client, live highlight of the executing step from
    action feedback, step/state/status display. State-driven UI (Run only in
    HOLD/MOVEIT); the panel never touches /set_robot_state — transitions are the
    executor's job. No editor by design (editing happens in VS Code).
    Verified: builds clean, RViz loads the panel without pluginlib errors.
    Manual UI acceptance (run/stop/highlight) pendi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
2026-06-12 fix(executor): TF listener needs its own spin thread for pose teaching
    The teach handler calls lookupTransform with a timeout from the main spin,
    which is the same thread that would feed the TF buffer — tf2 logged
    'Do not call lookupTransform with a timeout unless you are using another
    thread' and a cold buffer would always time out. Spin the TransformListener
    on its dedicated thread instead.
    [points.yaml, program_executor_node.cpp]
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2026-06-13 feat: Enhance program execution with blending and dry run options
    - Added support for blending through consecutive moves using the 'c_dis' parameter in the program loader.
    - Introduced new step types: 'ptp', 'lin', and 'circ' with appropriate validation and error handling.
    - Implemented UI elements in the program panel for enabling blending and dry run modes.
    - Created demo YAML files to showcase the new blending and circular motion capabilities.
    - Added comprehensive unit tests for the program loader, covering various scenarios including point validation and program execution.
    [program_executor_node.cpp]
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2026-08-18 fix: update joint_1 proportional gain to improve control response
    [r0192_ros2_control.xacro]
2026-09-04 Add Daisy Chain Driverlink-PCB documentation and design details
    - Introduced comprehensive documentation for the R0192 Daisy Chain Driverlink-PCB, detailing its context, functionality, design decisions, and safety considerations.
    - Documented key functional blocks including power distribution, CAN bus integration, and motor control.
    - Highlighted significant design changes such as the transition from MCP2515 to integrated CAN controller on ESP32-S3, and the use of SN65HVD230 as a native 3.3V CAN transceiver.
    - Included detailed specifications for components, power domains, connector types, and grounding concepts.
    - Added pre-fabrication checklist and firmware sequence for brake control.
    - Ou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
    [DriverDasyChain.kicad_pcb, DriverDasyChain.kicad_sch]
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2026-09-06 Refactor PCB documentation for R0192 Daisy Chain Driverlink-PCB
    - Updated the main documentation file `pcb_daisy_chain.md` to enhance clarity and structure, including detailed descriptions of functional blocks, design decisions, and GPIO assignments.
    - Removed obsolete references to the MCP2515 and clarified the use of the SN65HVD230 CAN transceiver.
    - Added detailed information on the brake control mechanism, including PWM control strategies and safety considerations.
    - Introduced a new lock file for KiCad project management.
    [DriverDasyChain.kicad_pcb, DriverDasyChain.kicad_sch]
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2026-09-11 Add Mouser order list for PCB components
    - Created a new CSV file containing the order details for various components needed for the PCB assembly.
    - Included manufacturer names, part numbers, quantities, designators, descriptions, and additional notes for each component.
    [DriverDasyChain.kicad_pcb, DriverDasyChain.kicad_sch, mouser_bestellung.csv]
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2026-09-12 Refactor PCB files and update documentation
    - Deleted lock file for the PCB layout.
    - Updated lock file for the schematic with new hostname.
    - Modified PCB daisy chain documentation to clarify connections and component specifications, including:
    - Revised homing sensor pinout.
    - Added new component for CAN-TVS protection.
    - Adjusted capacitor counts and specifications.
    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
    [DriverDasyChain.kicad_pcb, DriverDasyChain.kicad_sch]
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2026-09-13 Update PCB documentation and design for improved safety and performance
    - Clarified CAN pin assignments and wiring for GDS68 and RS05 drivers.
    - Added notes on the benign nature of terminal swapping at J4, J10, and J12.
    - Revised D1 placement explanation to emphasize its role and impact on braking performance.
    - Enhanced safety notes regarding the 48 V power supply and potential risks of incorrect wiring.
    - Specified the use of Nexperia PESD12VL2BT for CAN bus protection, detailing its specifications and placement.
    - Updated capacitor recommendations for 48 V buffer capacitors, emphasizing the importance of ripple current ratings and temperature resilience.
    - Adjusted BOM entries for capacit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
    [DriverDasyChain.kicad_pcb, DriverDasyChain.kicad_sch]
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2026-09-13 Update DriverDasyChain schematic and documentation for D5 TVS diode integration
    - Added D5 (TVS SMAJ58A) as a Q2 protection component in the schematic and updated its description in the markdown documentation.
    - Adjusted component placements and annotations for improved clarity and accuracy.
    - Revised text descriptions to reflect the new component's role and ensure consistency across documentation.
    - Corrected wire connections and positions in the schematic to enhance layout integrity.
    - Updated manufacturing recommendations and open points in the documentation to reflect the latest design changes.
    [DriverDasyChain.kicad_pcb, DriverDasyChain.kicad_sch]
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

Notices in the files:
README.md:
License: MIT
